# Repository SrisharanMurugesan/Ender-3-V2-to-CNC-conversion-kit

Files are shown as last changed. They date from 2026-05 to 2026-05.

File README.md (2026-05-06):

# Ender-3-V2-to-CNC-Conversion-Kit
<p align="center">
  
  
</p>

<p align="center">
  
  
</p>

## Description

This project features a modular CNC conversion of the Ender 3 V2 printer, transforming my old Ender 3 V2 into a belt-driven, gantry-style CNC. The design reimagines the stock aluminum extrusion frame, stepper-driven motion system, and V-wheel linear guidance architecture, while integrating a custom spindle assembly, rigid spoilboard, and structural gantry.

---

## Mechanical Overview

### Gantry Kinematics

<table>
  <tr>
    <td width="50%" valign="top">
        <strong>Axis Actuation & Functional Roles</strong><br><br>
        <strong>X-Axis (Red):</strong> Uses a belt-driven gantry designed for high-speed motion translation across the work area.<br><br>
        <strong>Y-Axis (Green):</strong> Focuses on translating the spindle across the bed, shifting the workpiece along the longitudinal plane.<br><br>
        <strong>Z-Axis (Blue):</strong> Uses a lead screw-driven assembly to manage tool depth, providing mechanical advantage over the controlled lifting forces.
    </td>
    <td width="50%" valign="top">
      Kinematic Diagram
    </td>
  </tr>
</table>

### V-Wheel System

<table>
  <tr>
    <td width="50%" valign="top">
      V-Wheel Guidance System
    </td>
    <td width="50%" valign="top">
      <strong>V-Wheel Constraint System</strong>
      <br><br>
      This system uses a triangular V-wheel layout to constrain motion along the aluminum extrusion. The two upper rollers and one lower roller create a three-point contact pattern that improves stability and reduces rocking under machining load. Ideler wheels are mounted directly to a Nema 17, both harvested from the V2
      <br><br>
     The V-wheels must be tightened enough to remove wobble, but not so tight that they create friction. This adjustment is important because loose rollers can cause deflection, vibration, and chatter during machining.
      <br><br>
      The Y-axis uses the same mechanism to constrain the spindle and promote movement along the Y-axis.
    </td>
  </tr>
</table>

## Spindle Assembly

<table>
  <tr>
    <td width="50%" valign="top">
      <strong>Spindle Mount and Z-Axis Integration</strong>
      <br><br>
      The spindle is mounted to the Z-axis carriage using a custom bracket designed to maintain alignment while cutting dense materials. The mount constrains the spindle body and positions the bit along the machine’s vertical axis.
      <br><br>
      The Z-axis uses a lead screw-driven assembly to control vertical motion and cutting depth. Because the spindle is placed to the side of the carriage, this region is succeptible to bending and vibration during machining.
      <br><br>
      The surrounding carriage and V-wheel system guide the spindle along the extrusion while resisting deflection.
    </td>
    <td width="50%" valign="top" align="center">
      Spindle Assembly
      <br>
    </td>
  </tr>
</table>
---

## Machining Capability

It can machine wood, plastics, and composites, with performance depending upon spindle speed and depth of cut. Because the system is belt-driven and V-wheel guided, it is not intended for heavy material removal. Harder materials such as aluminum require shallow passes, low cutting forces, and careful control of vibration. Steel machining should be done using extremely light passes.The main goal of this system is to demonstrate machining potential on a repurposed 3D printer and to cut carbon fiber drone frames, which is it highly capable of. 
Spindle assembly and spindle can be changed to accomodate different spindles, so one can machine different materials per individual specs.

---

## Tolerances and Fits

Printed parts were designed with 3D printing tolerances in mind and was made with intent to print on an A1. Clearance was added around bolt holes, sliding interfaces, and mating features to account for printer variation and easier assembly.

For most parts, a clearance of.1 mm is used.

---

### Bambu Lab A1 Recommended Settings

Recommended material: **PLA or ABS**

| Setting | Recommended Value |
|---|---|
| Layer Height | 0.16–0.20 mm |
| Nozzle Diameter | 0.4 mm |
| Wall Loops | 5–7 walls |
| Top Layers | 6–8 |
| Bottom Layers | 6–8 |
| Infill Density | 60–80% |
| Infill Pattern | Gyroid or Cubic |
| Print Speed | Standard or slower |
| Supports | Build plate only where needed |
| Brim | Recommended for tall or narrow parts |

For highly loaded parts, such as spindle mounts, V-wheel brackets, and gantry plates, use **70–80% infill** with at least **6 wall loops**. Parts should be oriented so that the main cutting loads act across the layer lines instead of pulling directly between layers.

---

### Bill of Materials

1) M3 Bolts
2) M4 Bolts
3) M5 Bolts
4) Spindle of choice (500W Spindle was used by me)
5) Ender 3 V2

## Author's Note

This project was created to explore my design capabilities through iterative design process. I started with my old Ender 3 V2, which was my first 3D printer, and admittingly it was quite neglected once I built my Worlds Fastest Printer and bought an A1. Therefore, I was inspired to reinvent this printer into something as beautiful as it once was. I also needed a CNC to cut carbon fiber drone frames, so I thought why not. Rather than designing a CNC machine from scratch, I worked within the constraints of reusing the printer’s existing frame, motion system, motors, electronics, and hardware. Aside from standard M3, M4, and M5 bolts, the rest of the conversion was designed solely using parts already available from the printer and custom 3D printed components. This constraint made the project more interesting because every design choice had to account for stiffness, load paths, vibration, manufacturability, and the mechanical limits of the original platform. The goal was to transform a familiar machine into something more capable while pushing my understanding of mechanical design. I hope to build it within the weeks coming and plan to make reports once I do. I hope you enjoy.

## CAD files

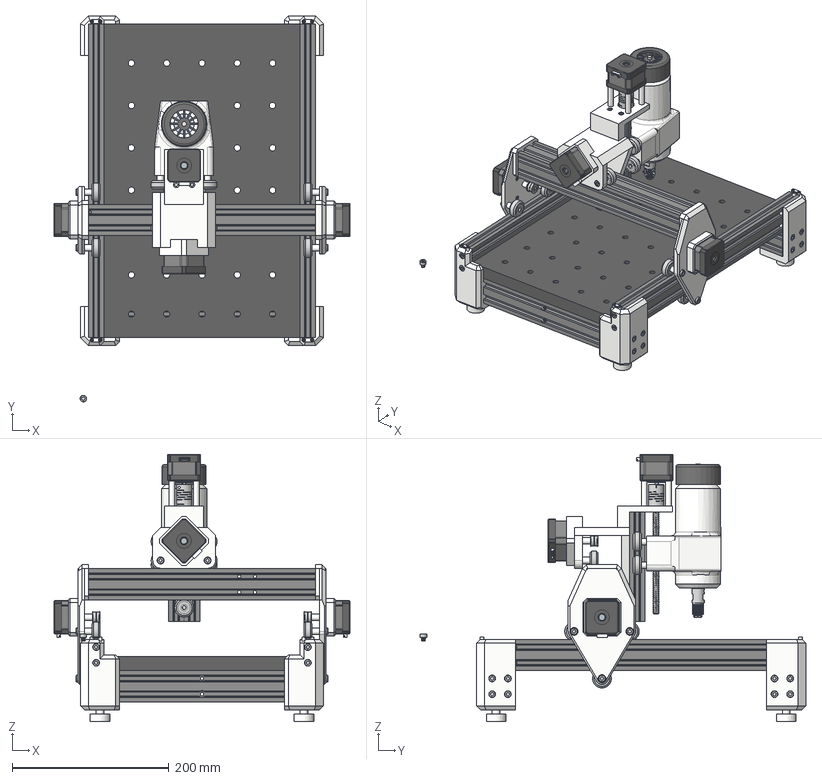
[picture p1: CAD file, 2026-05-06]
Ender3-V2_CNC_Assembly/Final Assembly.step
377.4 x 491.9 x 340.7 mm
Extrusion_base-LR x 2
Extrusion_Zaxis-R
Extrusion_Zaxis-L
Hole Jig A x 2
Hole Jig B x 2
Roller Standoff x 9
Roller_Polymer_Axis x 13
Side Plate A x 2
Extrusion_Y-Axis
Bearing_ideler_Belt Tension x 6
Idler Standoff x 3
Nema 17 x 4
Feet x 4
Belt Clip x 4
Y Harness
Standoff x 4
Lead Screw_8mm Threaded Rod Trapezoidal_Z Axis
Acoplamento Elastico_Valor predeterminado
SpoilBoard
Extrusion_Top_Ganter x 2
Z Mount
Fitting_brass_Z Axis_Acme Screw
Roller Standoff Z x 4
1-8 Centre Collet
500W Spindle Motor
ALLEN_KEY_BOLT_M5 x 45
ALLEN_KEY_BOLT__M3 x 16
ALLEN_KEY_BOLT_STD x 8

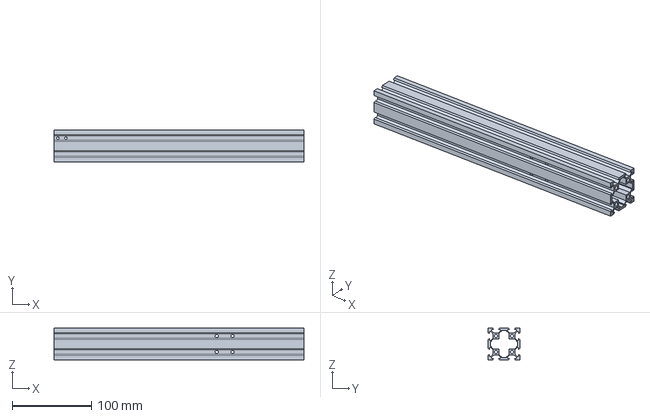
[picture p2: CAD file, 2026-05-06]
Ender3-V2_CNC_Parts/Spindle Assembly.step
315.0 x 40.0 x 40.0 mm

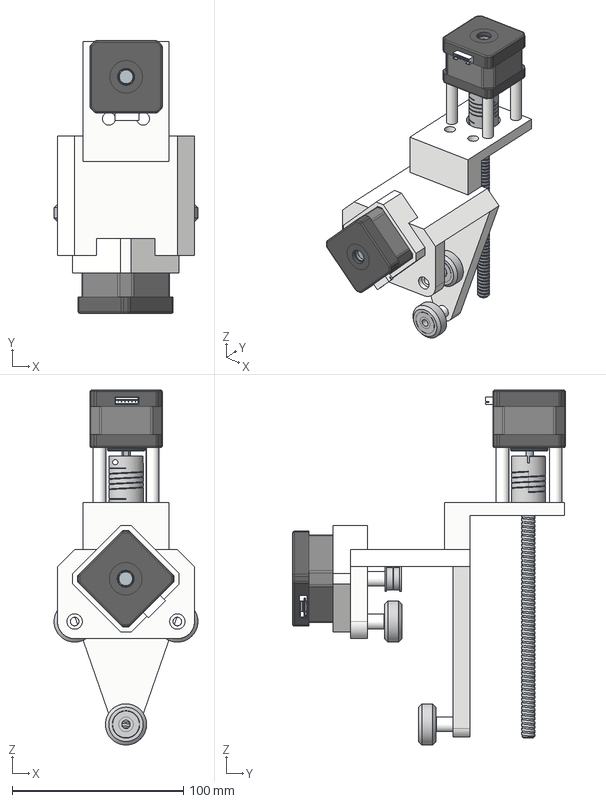
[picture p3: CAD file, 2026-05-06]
Ender3-V2_CNC_Parts/Z SubAssembly-dup.step
84.1 x 159.3 x 207.4 mm
Roller Standoff x 3
Y Harness
Roller_Polymer_Axis x 3
Idler Standoff
Bearing_ideler_Belt Tension x 2
Standoff x 4
Nema 17 x 2
Lead Screw_8mm Threaded Rod Trapezoidal_Z Axis
Acoplamento Elastico_Valor predeterminado

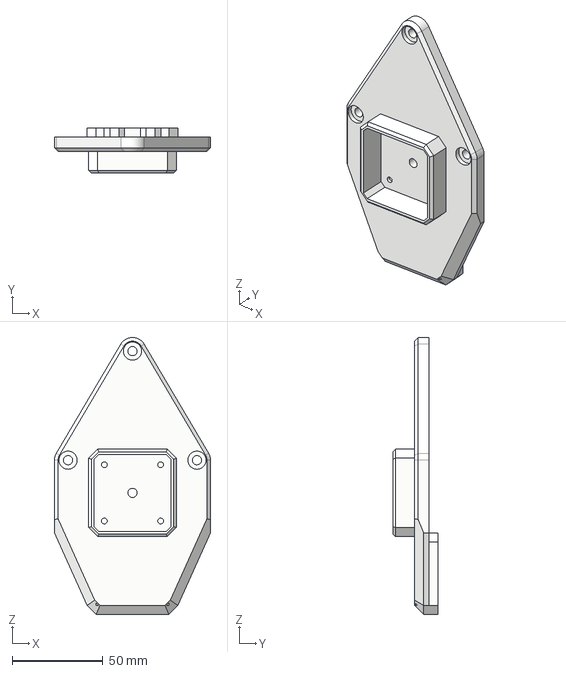
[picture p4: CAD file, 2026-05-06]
Ender3-V2_CNC_Parts/Side Plate A.step
86.0 x 25.0 x 152.6 mm

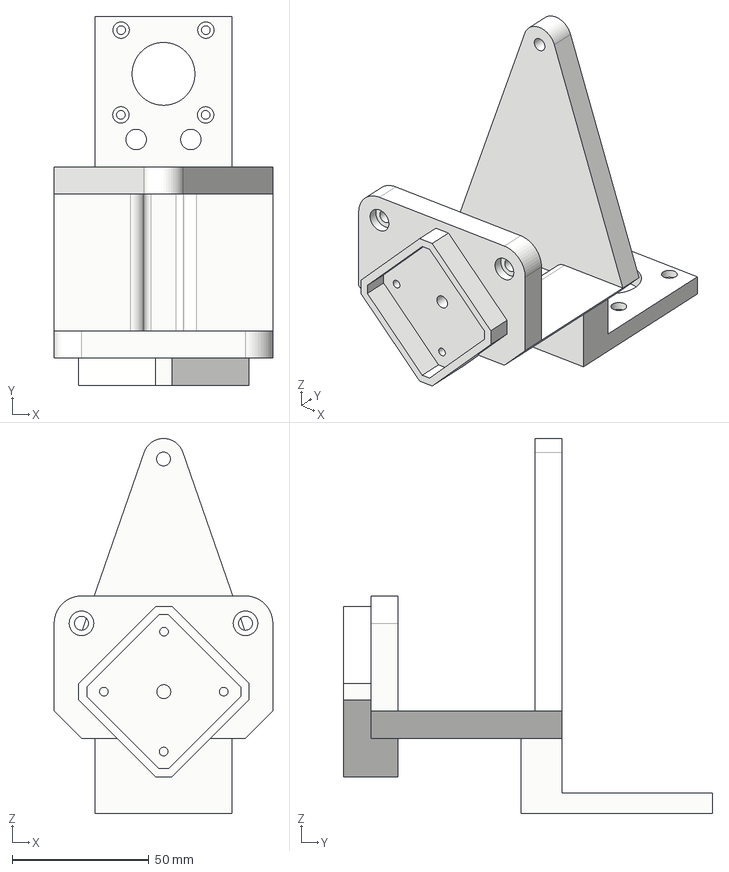
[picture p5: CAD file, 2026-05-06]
Ender3-V2_CNC_Parts/Y Harness.step
80.0 x 135.0 x 137.2 mm

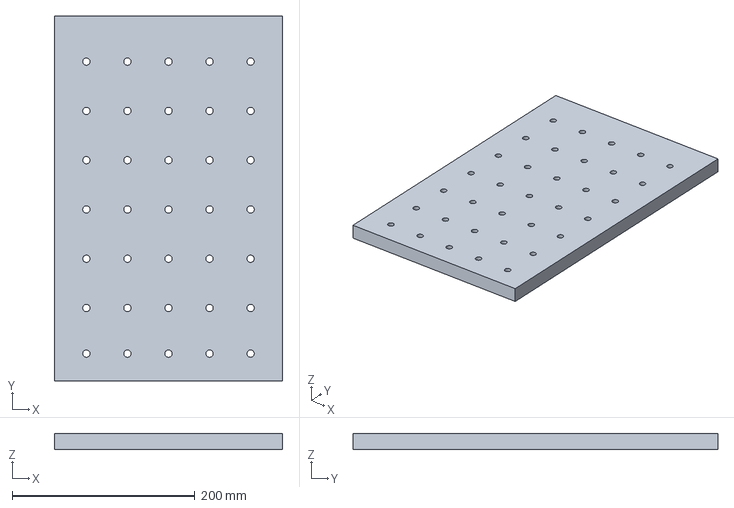
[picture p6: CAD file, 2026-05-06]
Ender3-V2_CNC_Parts/SpoilBoard.step
250.0 x 400.0 x 18.0 mm

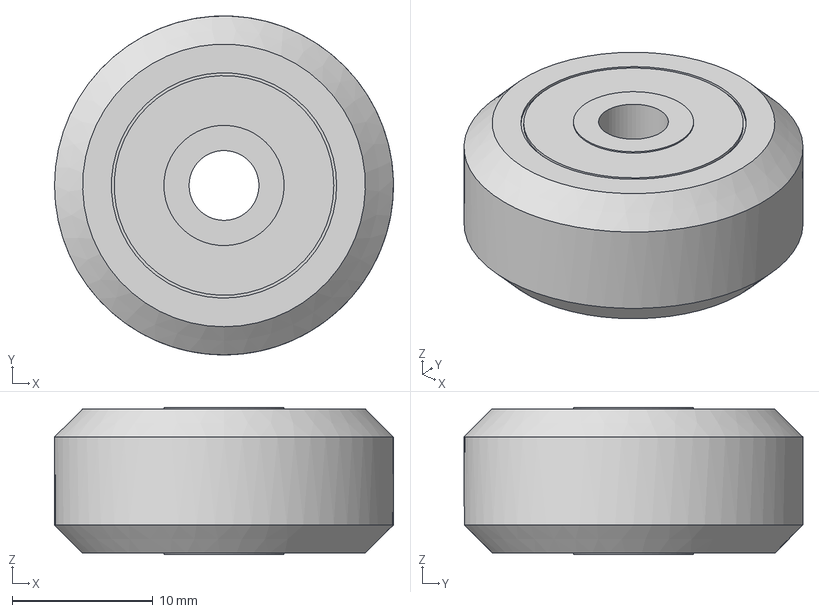
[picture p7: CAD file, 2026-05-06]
Ender3-V2_CNC_Parts/Roller.step
24.1 x 24.1 x 10.5 mm

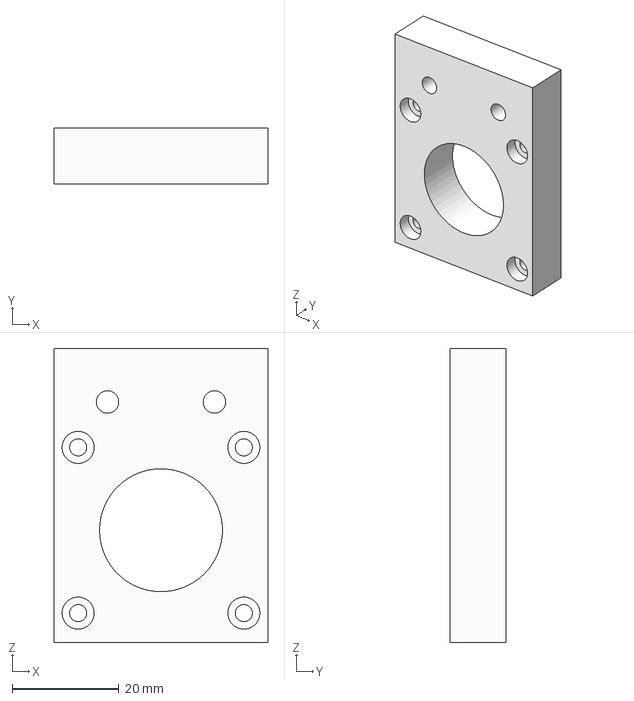
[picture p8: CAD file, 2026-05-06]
Ender3-V2_CNC_Parts/Z Axis Mount.step
40.0 x 10.5 x 55.0 mm

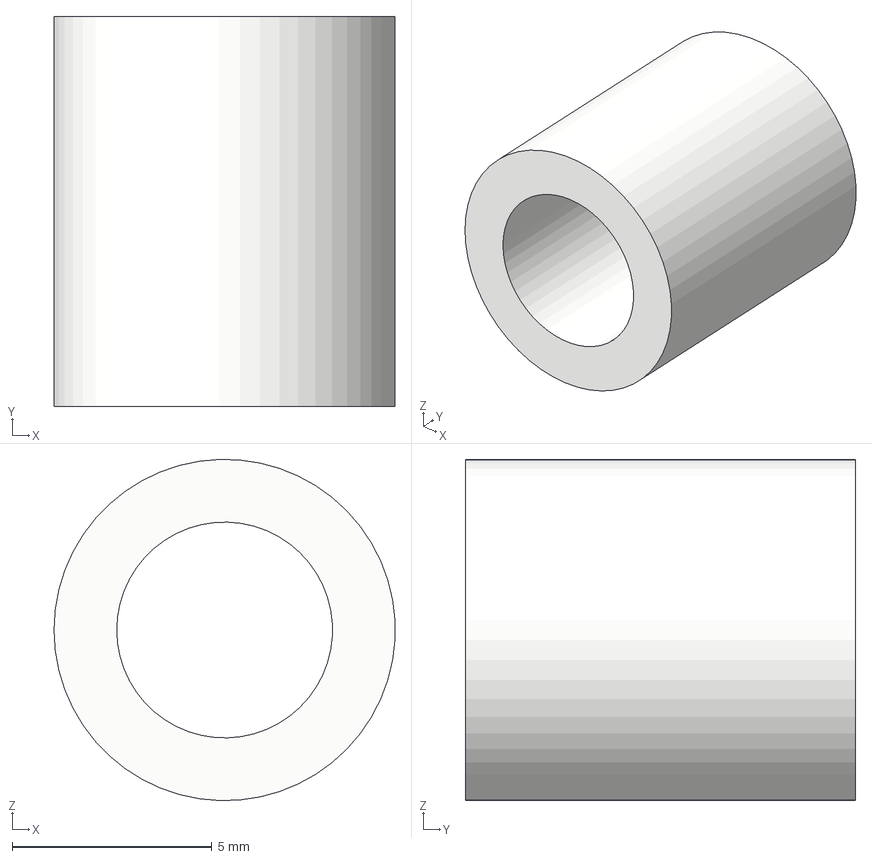
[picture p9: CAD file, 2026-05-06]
Ender3-V2_CNC_Parts/Roller Standoff.step
8.53 x 9.77 x 8.54 mm

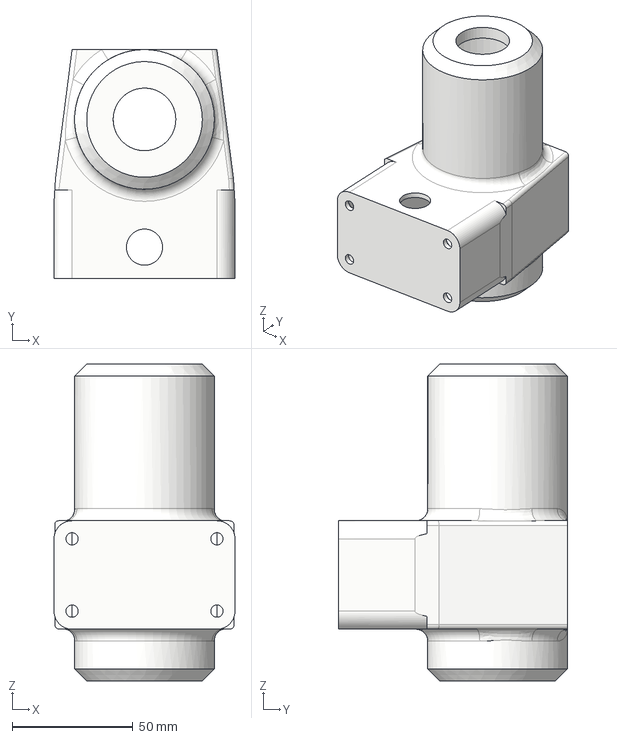
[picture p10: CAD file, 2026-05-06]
Ender3-V2_CNC_Parts/Z Mount.step
75.1 x 95.0 x 131.5 mm

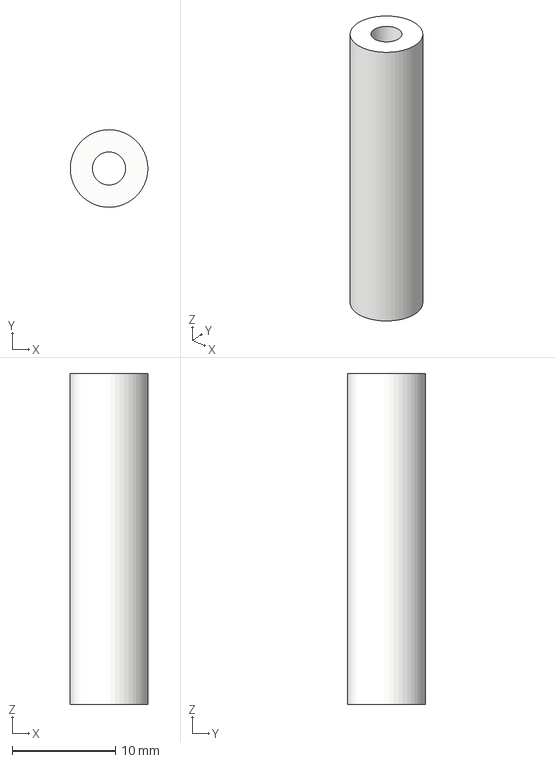
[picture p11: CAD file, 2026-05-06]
Ender3-V2_CNC_Parts/Standoff.step
7.49 x 7.50 x 32.0 mm

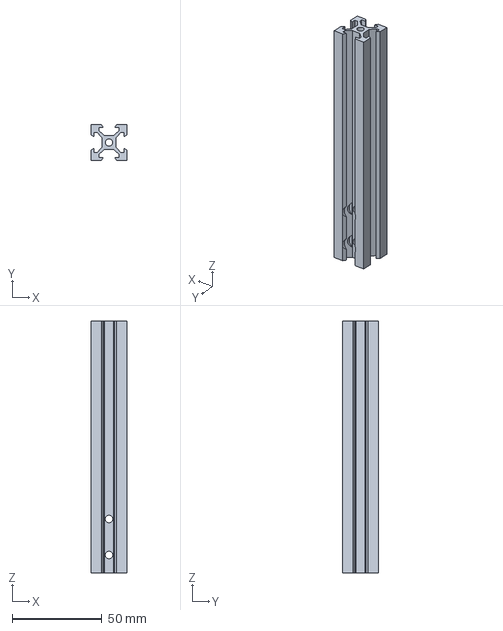
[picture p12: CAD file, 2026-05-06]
Ender3-V2_CNC_Parts/Z Extrusion.step
20.0 x 20.0 x 140.0 mm

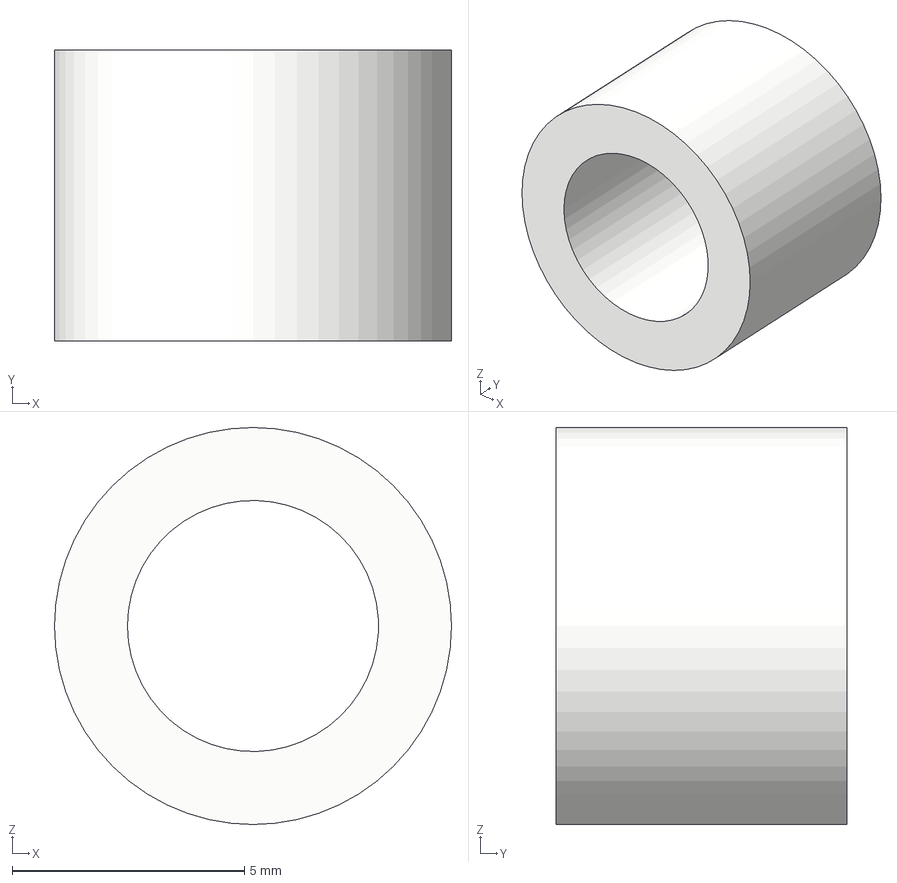
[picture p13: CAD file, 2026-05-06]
Ender3-V2_CNC_Parts/Roller Standoff Z.step
8.54 x 6.27 x 8.54 mm

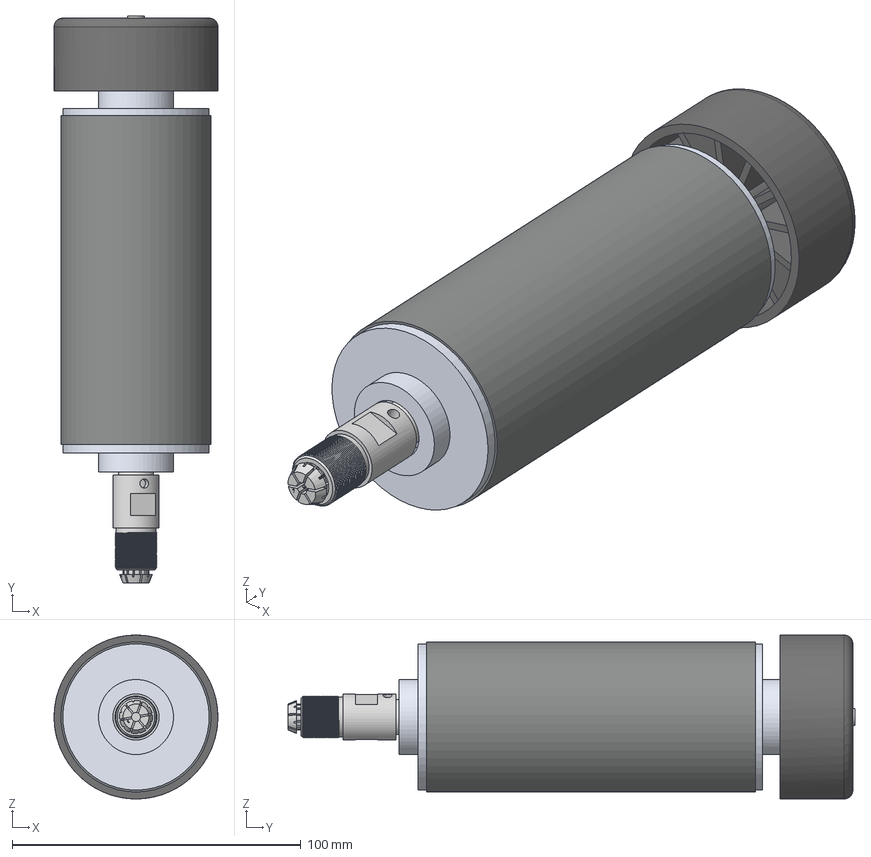
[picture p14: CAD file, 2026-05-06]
Ender3-V2_CNC_Parts/500W Spindle Motor with ER11 Collet-dup.step
56.8 x 196.5 x 56.8 mm
1-8 Centre Collet
500W Spindle Motor

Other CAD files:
Ender3-V2_CNC_Parts/Z SubAssembly.step
Ender3-V2_CNC_Parts/Hole Jig B.step
Ender3-V2_CNC_Parts/Ender3-V2_Bearing_ideler_Belt Tension.step
Ender3-V2_CNC_Parts/500W Spindle Motor with ER11 Collet.step
Ender3-V2_CNC_Parts/Allen key bolt M3.step
Ender3-V2_CNC_Parts/Allen key bolt M4.step
Ender3-V2_CNC_Parts/Allen key bolt M5.step
Ender3-V2_CNC_Parts/Belt Clip.step
Ender3-V2_CNC_Parts/Feet.step
Ender3-V2_CNC_Parts/Fitting_brass_Z Axis_Acme Screw.step
Ender3-V2_CNC_Parts/Hole Jig A.step
Ender3-V2_CNC_Parts/Idler Standoff.step
Ender3-V2_CNC_Parts/Lead Screw Coupler SubAssembly-dup.step
Ender3-V2_CNC_Parts/Lead Screw Coupler SubAssembly.step
Ender3-V2_CNC_Parts/Nema 17.step
Ender3-V2_CNC_Parts/T8 Coupler & Lead Screw.step
